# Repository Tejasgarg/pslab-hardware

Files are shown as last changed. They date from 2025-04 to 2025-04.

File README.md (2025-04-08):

# PSLab-Mini-hardware

This branch is dedicated to prototyping the PSLab-Mini board and push out a working board that has functionalities of oscilloscope, multimeter and if time allows it, a logic analyser.

## PCB Layout
* I made a new PCB layout by first updating and removing components from the PSLab Schematic.
* The changed schematic was imported into a fresh PCB editor file in KiCAD.
* Made new edge cuts that provide a smaller footprint to the board compared to the current board
* Placed all the components and made a 4-layer PCB
* The 4 layers are as follows:
     * F.Cu(Front Copper) - Consists of signal routings
     * GND(Ground) - Consists of a ground pour in the entire layer
     * VDDA(Power) - Consists of a copper pour that transmits power to the majority of the components
     * B.Cu(Bottom Copper) - Also consists of the routing
* Used both through and buried vias:
     * Buried Vias - Used buried vias for connecting the components to the ground and power layer
     * Through Vias - Used Through vias for connecting the top and bottom copper layer for essentially connecting and routing wherever there was a blockage 
       due to already present routes

Front Side                        | Back Side
 -------------------------------- | ----------------------------------
Screenshot 2025-04-08 at 3 04 56 PM copy | Screenshot 2025-04-08 at 3 05 13 PM copy

## New Schematic
The new schematic has been made on top of the current schematic for a quicker prototype and clearly shows all the components removed in the current PSLab board, and explains the reasoning behind the removal of each. 

PSLab mini

## Platform

* Microcontroller Platform : [PIC24EP256GP204](http://www.microchip.com/wwwproducts/en/PIC24EP256GP204)
* IDE: [MPLABX IDE v3.35](http://www.microchip.com/mplab/mplab-x-ide) (Supported on Linux/Windows/Mac)
* Compiler: [MPLAB® XC16 Compiler](http://www.microchip.com/mplab/compilers)
* Programming Tool: [PICkit™ 3 In-Circuit Debugger](http://www.microchip.com/Developmenttools/ProductDetails.aspx?PartNO=PG164130)

## New parts list

* [PIC24EP256GP204](http://www.microchip.com/wwwproducts/en/PIC24EP256GP204) - Microcontroller
* [MCP6S21](http://www.microchip.com/wwwproducts/en/mcp6s21) - Programmable gain amplifier
* [TL082](http://www.ti.com/product/TL082) - 2 channel Op-Amp
* [CP2102N-A02-GQFN24](https://www.silabs.com/documents/public/data-sheets/cp2102n-datasheet.pdf) - USB-UART bridge
* [SP0503BAHTG](https://m.littelfuse.com/~/media/electronics/datasheets/tvs_diode_arrays/littelfuse_tvs_diode_array_sp05_datasheet.pdf.pdf) - ESD protector

* 0.5 A Fuse
* Assorted resistors, capacitors & diodes

## Hardware Specs

* 3-Channel up to 2MSPS Oscilloscope. Software selectable amplification stages
* 12-bit Voltmeter. Input ranges from +/-10 mV to +/-16 V
* Capacitance Measurement. pF to uF range
* UART data buses for secondary modules 

## Feature list for PSLab-Mini

### Oscilloscopes

One of the main features of PSLab is the 3-channel Oscilloscope, which can monitor analog inputs at a maximum of 2 million samples per second.
In PSLab mini, this will be retained but with the following changes:
* Reduce the channels from 3 to 2 channels oscilloscope to reduce the components and cost
* Aim at increasing the max sampling rate

### Measurement Functions

* Frequency counter tested up to 16 MHz.
* Capacitance Measurement. pF to uF range
* Resistance measurement
* Voltmeter with a range of +/-10 mV to +/-16 V

### Other useful tools

* UART outputs
* Graphical Interfaces for Oscilloscope, Multimeter, streaming data and several experiments developed that use a common framework which drastically reduces code required to incorporate control and plotting widgets.

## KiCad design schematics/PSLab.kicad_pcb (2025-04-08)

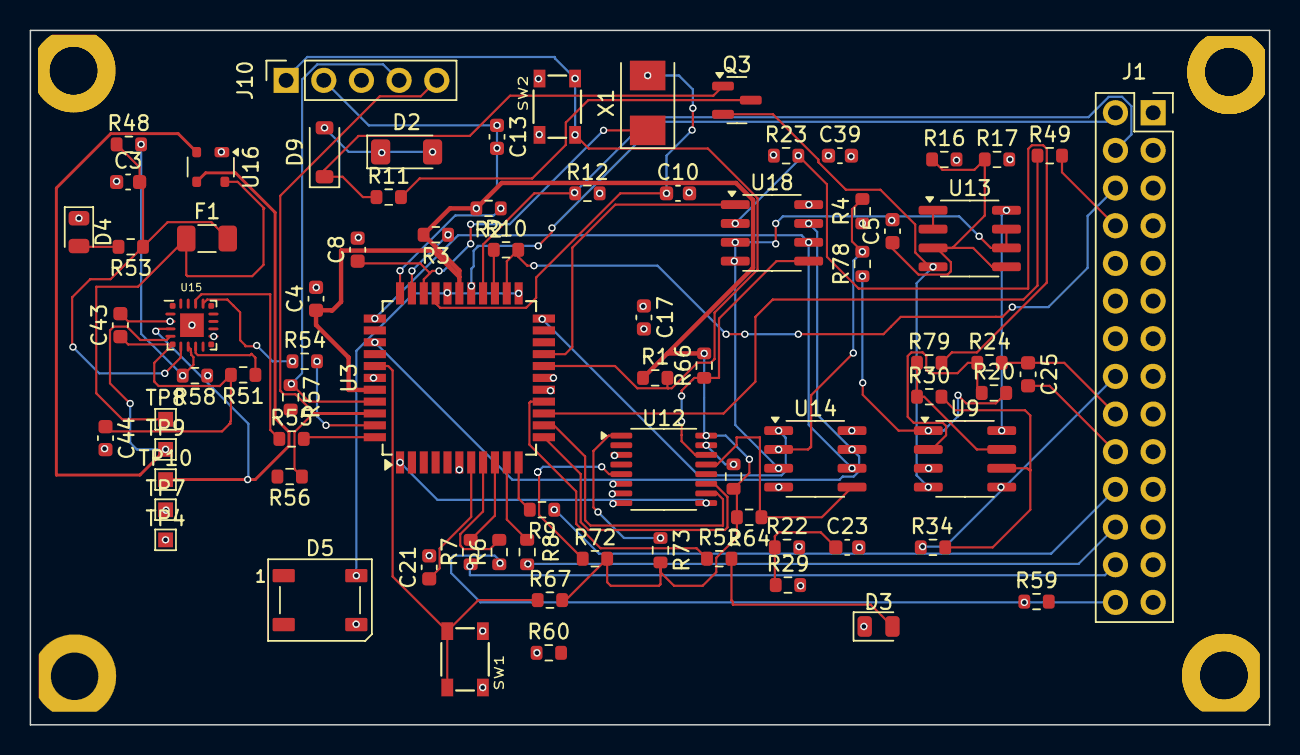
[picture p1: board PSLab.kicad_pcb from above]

Board: 4 copper layers, 83.6 x 46.8 mm, 82 parts (0 on the bottom side), 71 nets.

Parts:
C3, C4, C13, C17, C25, C39, C43: 100nF; C_0603_1608Metric
C5, C23: 10nF; C_0603_1608Metric
C8, C10: 12pF; C_0603_1608Metric
C21, C44: 10uF; C_0603_1608Metric
D2: 6.8V; D_MiniMELF
D3: GREEN; LED_0805_2012Metric
D4: BLUE; LED_0805_2012Metric
D5: WS2812B; LED_WS2812B_PLCC4_5.0x5.0mm_P3.2mm
D9: 1N4148W; D_SOD-123
F1: 1A; Fuse_1206_3216Metric
J1: DoublePins; PinSocket_2x14_P2.54mm_Vertical
J10: Programmer; PinSocket_1x05_P2.54mm_Vertical
MH4, MH4#2, MH4#3, MH4#4: M; TwoSided_MPad
Q3: MMBT3906; SOT-23
R1, R4, R10, R16, R17, R23, R29, R58, R64, R66, R67, R71, R72, R73, R78, R79: 10k; R_0603_1608Metric
R2, R3, R12, R48, R52, R53, R59, R60: 5.1k; R_0603_1608Metric
R6, R7, R8, R9, R49: 200; R_0603_1608Metric
R11, R51: 1k; R_0603_1608Metric
R20, R30: 200k; R_0603_1608Metric
R22: 12k; R_0603_1608Metric
R24, R34: 1M; R_0603_1608Metric
R54, R55, R56, R57: 18; R_0603_1608Metric
SW1, SW2: SW_MEC_5E; button_SPST_3x4x2.5
TP4, TP7: GND; TestPoint_Pad_1.0x1.0mm
TP8: VBUS; TestPoint_Pad_1.0x1.0mm
TP9: D-; TestPoint_Pad_1.0x1.0mm
TP10: D+; TestPoint_Pad_1.0x1.0mm
U3: PIC24EP256GP204; TQFP-44_10x10mm_P0.8mm
U9, U13: TL082; SOIC-8_3.9x4.9mm_P1.27mm
U12: 74HC4051; TSSOP-16_4.4x5mm_P0.65mm
U14, U18: MCP6S21; SOIC-8_3.9x4.9mm_P1.27mm
U15: CP2102N-xxx-xQFN20x; QFN-20_EP_3x3_Pitch0.5mm
U16: SP0503BAHT; SOT-143
X1: 12MHz; Crystal_SMD_5032-2Pin_5.0x3.2mm

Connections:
+3.3V: C4.1, C13.1, J10.2, R1.1, R2.2, R3.2, R64.2, R66.2, R67.2, R71.2, R72.2, R73.2, U3.28 (VDD), U3.40 (VDD), U12.16 (VCC)
+6V: U9.8 (V+), U13.8 (V+)
-6V: Q3.2 (E), U9.4 (V-), U13.4 (V-)
-9V: Q3.3 (C), R11.2
/CAP: J1.6, R10.2, U3.24 (PGED1|AN5|C1IN1-|RP35|RB3)
/CP2102_Vreg: C43.1, C44.1, R51.2, U15.6 (VDD)
/D+: TP10.1, U15.4 (D+), U16.3 (K)
/D-: TP9.1, U15.5 (D-), U16.2 (K)
/LA1_: R6.2, U3.8 (RP42|RB10)
/LA2_: R7.2, U3.9 (RP43|RB11)
/LA3_: R8.2, U3.10 (RPI44|RB12)
/LA4_: R9.2, U3.11 (RPI45|CTPLS|RB13)
/OSC_IN: C10.1, U3.30 (OSC1|CLKI|RA2), X1.2
/OSC_OUT: C8.1, U3.31 (OSC2|CLKO|RA3), X1.1
/OSC_REF1: U13.6 (-), U13.7, U14.3 (VREF), U18.3 (VREF)
/OSC_REF2: C23.1, R22.1, R29.1
/RES: J1.4, R12.1, U3.26 (AN7|C3IN1-|C4IN1-|RC1)
/RxD: R54.2, U3.43 (RP39|INT0|RB7)
/SCL: R2.1, U3.33 (SCL2|RP36|RB4)
/SDA: R3.1, U3.32 (SDA2|RPI24|RA8)
/TxD: R55.2, U3.44 (TCK|ASCL1|RP40|T4CK|RB8)
/VBusSense: R48.2, R58.2, U15.8 (VBUS)
/VINPUT: C3.2, F1.2, R48.1, R53.1, U15.7 (VregIn)
/VOL: J1.2, U3.27 (AN8|C3IN1+|RC2)
/VUSBIN: F1.1, TP8.1, U16.4 (K)
ACH1: C25.2, J1.20
BOOT: R67.1, SW1.1, SW1.2, U3.38 (SCL1|RPI53|RC5)
CH1: C25.1, J1.18, R24.2
CH1_IN: U3.22 (PGEC3|AN3|OA1OUT|RPI33|RB1), U14.1 (OUT)
CH2: J1.16, R34.1
CH2_IN: U3.19 (AN0|OA2OUT|RA0), U18.1 (OUT)
CS1: R64.1, U12.13 (A0), U14.5 (CS)
CS2: R66.1, U12.14 (A1), U18.5 (CS)
CS3: R71.1, U12.15 (A2)
CS.CH1: U3.12 (TDO|RA10), U12.11 (S0)
CS.CH2: U3.13 (TDI|RA7), U12.10 (S1)
CS.CH3: U3.1 (TMS|ASDA1|RP41|RB9), U12.9 (S2)
FQy: J1.8, R49.2
GND: C3.1, C4.2, C5.2, C8.2, C10.2, C13.2, C17.2, C21.2, C23.2, C39.2, C43.2, C44.2, D2.1 (K), D3.1 (K), D4.1 (K), D5.3 (VSS), J1.1, J1.3, J1.5, J1.7, J1.9, J1.11, J1.13, J1.15, J1.17, J1.19, J1.21, J1.23, J1.25, J1.27, J10.3, MH4.1, MH4#2.1, MH4#3.1, MH4#4.1, R17.2, R29.2, R58.1, R59.1, R60.1, SW1.3 (K), SW1.4 (A), SW2.3 (K), SW2.4 (A), TP4.1, TP7.1, U3.6 (GND), U3.16 (GND), U3.29 (GND), U3.39 (GND), U9.3 (+), U9.5 (+), U12.3 (A), U12.6 (~E), U12.7 (VEE), U12.8 (GND), U14.4 (GND), U15.3 (GND), U15.12 (GND), U15.21 (GND), U16.1 (A), U18.4 (GND)
LA1: J1.28, R6.1
LA2: J1.26, R7.1
LA3: J1.24, R8.1
LA4: J1.22, R9.1
MCLR: J10.1, R1.2, SW2.1, SW2.2, U3.18 (~MCLR)
unnamed: D2.2 (A), D9.2 (A)
unnamed: D3.2 (A), R52.2
unnamed: D4.2 (A), R53.2
unnamed: D9.1 (K), Q3.1 (B), R11.1
unnamed: R20.2, R78.1, U9.1
unnamed: R30.1, R79.1, U9.7
unnamed: R10.1, U3.25 (AN6|OA3OUT|C4IN1+|RC0)
unnamed: R49.1, U3.14 (RPI46|T3CK|RB14)
unnamed: C21.1, U3.7 (VCAP)
unnamed: R20.1, R24.1, U9.2 (-)
unnamed: R30.2, R34.2, U9.6 (-)
unnamed: R72.1, U12.5 (A5)
unnamed: C5.1, R16.1, R17.1, U13.3 (+), U13.5 (+)
unnamed: U13.1, U13.2 (-)
unnamed: R4.2, R78.2, U14.2 (CHA)
unnamed: R51.1, U15.9 (RSTb)
unnamed: R54.1, U15.17 (RXD)
unnamed: R55.1, U15.18 (TXD)
unnamed: R23.2, R79.2, U18.2 (CHA)
PGC2: J10.5, R56.1, U3.42 (PGEC2|ASCL2|RP38|RB6)
PGD2: J10.4, R57.1, U3.41 (PGED2|ASDA2|RP37|RB5)
RGB: D5.4 (DIN), U3.23 (PGEC1|AN4|C1IN1+|RPI34|RB2)
SCK: U3.36 (SCK1|RPI51|RC3), U14.7 (SCK), U18.7 (SCK)
SDO: U3.34 (SDO1|RP20|T1CK|RA4), U14.6 (SDI), U18.6 (SDI)
SPI.CS: R73.1, U12.1 (A4)
STAT: R52.1, U3.15 (RPI47|T5CK|RB15)
VDDA: C17.1, C39.1, R4.1, R12.2, R16.2, R22.2, R23.1, U3.17 (AVDD), U14.8 (VDD), U18.8 (VDD)
